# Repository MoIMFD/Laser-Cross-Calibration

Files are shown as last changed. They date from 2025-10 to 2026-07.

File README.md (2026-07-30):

# Laser Cross Calibration

A Python framework for non-sequential optical ray tracing, built to calibrate volumetric PIV (Particle Image Velocimetry) cameras via laser cross-calibration. It includes hardware control for driving a motorized dual-laser stage.

> **Status:** Research-grade, actively used at IMFD. Core ray tracing, materials, geometry, and optimization are stable. Some workflow steps (see [Known Gaps](#known-gaps)) still require manual glue code — see [Project Status](#project-status).

## Table of Contents

- [Concept](#concept)
- [Project Status](#project-status)
- [Repository Layout](#repository-layout)
- [Installation](#installation)
- [Core Concepts](#core-concepts)
- [Quickstart](#quickstart)
- [Inverse Optimization (Stage Positioning)](#inverse-optimization-stage-positioning)
- [Pipe Center Finder](#pipe-center-finder)
- [Hardware Control (`lcc-control-gui`)](#hardware-control-lcc-control-gui)
- [Development](#development)
- [Validation](#validation)
- [Known Gaps](#known-gaps)
- [License](#license)

## Concept

Laser cross calibration determines the 3D world position of the point where two laser beams intersect, and uses that as a calibration reference for cameras. By moving the intersection point through a measurement volume and photographing it, camera calibration can be performed without physically inserting a target into the flow — which matters when the target volume is a closed vessel, a pressurized cell, or otherwise hard to access.

For a beam through a single flat window, the intersection point can be computed analytically. Real setups usually involve several refractive interfaces (tank walls, immersion fluid, cylindrical windows, curved geometry), where refraction at each interface shifts the intersection unpredictably. This package solves that with **non-sequential ray tracing**: rays are propagated through an arbitrary set of optical interfaces, refracting or reflecting at each one according to Snell's law, until they either exit the system or run out of interfaces to hit.

The output is an estimate of the intersection point in world coordinates, accurate enough to serve as an initial calibration that can be refined with volume self-calibration or similar downstream methods.

## Project Status

| Area | State |
|---|---|
| Ray tracing engine (`tracing/`) | Stable, used in production |
| Surfaces: plane, cylinders, triangulated STL (`surfaces/`) | Stable |
| Materials: constant index, Sellmeier glass, mixtures (`materials/`) | Stable |
| Laser sources: single beam, dual-beam stage (`sources/`) | Stable |
| Inverse optimization (target point → stage position) (`optimization/`) | Working, see `examples/advanced-curved-geometry.ipynb` |
| Pipe center finder (`geometry/`) | Working, used for post-hoc pipe geometry extraction |
| Visualization (`visualization/`) | Working (Plotly-based interactive scenes) |
| Hardware control GUI (`lcc-control-gui/`) | Functional, production-tested with Marlin firmware |
| G-code generation from optimization results | Manual bridge only, no library API — see [Known Gaps](#known-gaps) |

Validated against published experimental data (Gunady et al., 2024) — see [Validation](#validation).

## Repository Layout

```
src/laser_cross_calibration/   Core ray tracing library (this package)
├── tracing/                   OpticalSystem, OpticalInterface, OpticalRay, RayTracer
├── surfaces/                  Plane, cylinders, triangulated (STL) surfaces
├── materials/                 Refractive index models + material registry
├── sources/                   Laser beam source definitions
├── optimization/              Inverse kinematics (target point -> stage position)
├── geometry/                  Pipe center finder (chord-fitting geometry)
└── visualization/             Plotly-based 3D scene rendering

lcc-control-gui/                Separate installable package (uv workspace member)
├── src/lcc_control_gui/       PySide6 GUI + StageController for Marlin-based stages
├── firmware/                  ESP32/Arduino mock Marlin firmware for testing without hardware
└── README.md                  Full GUI usage guide — read this before running the stage

examples/                       Jupyter tutorials
├── introduction-tutorial.ipynb  Start here: flat-plate system, Gunady et al. validation
├── advanced-curved-geometry.ipynb  STL geometry, sampling + Optimizer, calibration grid, G-code
└── stl-files/                  Example STL geometry used by the notebooks above

tests/                          pytest suite for the core library
```

## Installation

Requires **Python ≥ 3.12**. The project uses [uv](https://docs.astral.sh/uv/) and is set up as a workspace with `lcc-control-gui` as a member, so a single `uv sync` installs both the ray tracing library and the GUI:

```bash
git clone git@gitlab.hrz.tu-chemnitz.de:fluid-imfd/experiment/laser-cross-calibration.git
cd laser-cross-calibration
uv sync
```

To also pull the optional example-notebook dependency (mermaid diagram rendering):

```bash
uv sync --extra examples
```

Without `uv`, a standard editable install also works:

```bash
pip install -e .
pip install -e ./lcc-control-gui   # only if you need the hardware GUI
```

The core library depends on [`hazy-frames`](https://pypi.org/project/hazy-frames/) (published on PyPI) for coordinate frame management — no separate setup needed, it installs like any other dependency.

## Core Concepts

### Interfaces, not ambient media

Rather than tracking "what medium is the ray currently in" globally, every `OpticalInterface` explicitly names the material on both sides:

```python
OpticalInterface(
    geometry=plane_surface,
    material_pre=lcc.materials.AIR,             # side the ray approaches from
    material_post=lcc.materials.GLASS_FUSED_SILICA,  # side the ray continues into
)
```

**The surface normal must point from `material_post` toward `material_pre`** — i.e., outward from the transmitted medium:

Requires Python >= 3.12. Managed with [uv](https://docs.astral.sh/uv/).

```bash
# Install the core library in development mode
uv sync

# Optionally install the control GUI
uv pip install -e ./lcc-control-gui

# Install example notebook dependencies
uv sync --extra examples
```

This resolves what would otherwise be ambiguous for nested surfaces or re-entrant geometry, and matches how optical engineers usually reason about coatings and interfaces. Getting a normal backwards is the most common source of "rays refract the wrong way" bugs — when working from STL files, check normals visually in Blender before importing:

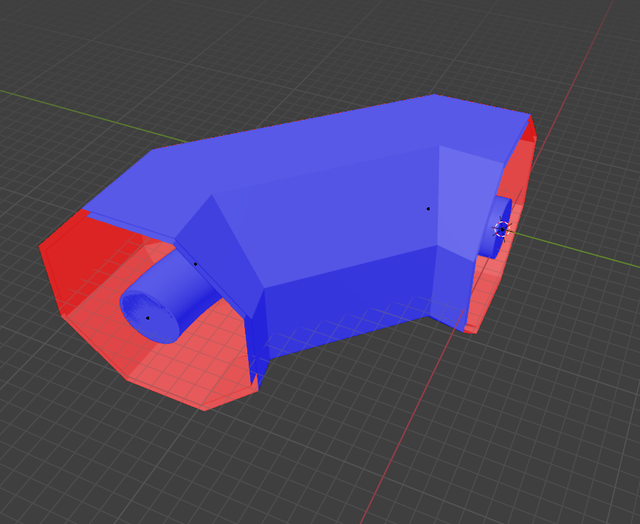
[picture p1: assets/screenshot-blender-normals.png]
Surface normal visualization in Blender


<details>
<summary>Checking normals in Blender</summary>

1. **Import your STL file**: `File -> Import -> STL`
2. **Enter Edit Mode**: select the object, press `Tab`
3. **Enable face orientation overlay**: overlay options (top-right) → check "Face Orientation"
   - Blue faces = normal points toward camera (outward)
   - Red faces = normal points away from camera (inward)
4. Optionally enable "Normals" → "Face" to see the actual vectors

For an air-to-glass interface, the normal should point toward air (outward from glass); for glass-to-air, toward glass.
</details>

### Building blocks

| Concept | Class | Role |
|---|---|---|
| Geometry | `Surface` (`Plane`, `InfiniteCylinder`, `FiniteCylinder`, `EllipticCylinder`, `TriSurface`) | Shape and location of a boundary. `TriSurface` loads STL meshes, with optional smooth (Gouraud-style) normal interpolation. |
| Material | `BaseMaterial` (`ConstantMaterial`, `SellmeierGlass`, `WaterGlycerolMixture`) | Refractive index, optionally wavelength-dependent. Look one up from the built-in registry via `lcc.materials.get_material("BK7")`. |
| Interface | `OpticalInterface` | Pairs a `Surface` with `material_pre` / `material_post`. |
| System | `OpticalSystem` | Container for all interfaces a ray can hit. `final_propagation_distance` controls how far rays travel after the last interface, so intersections downstream can still be found. |
| Source | `LaserSource` (`SingleLaserSource`, `DualLaserStageSource`) | Where beams originate. `DualLaserStageSource` models two beams fixed to a common stage origin (`arm1`/`arm2` offsets, one direction each) — the actual use case for cross-calibration. |
| Tracer | `RayTracer` | Traces sources through a system non-sequentially (closest-hit-first) and locates beam intersections. |
| Scene | `Scene` | Interactive Plotly 3D visualization of systems, sources, traced rays, and points. |

Coordinate handling goes through [`hazy`](https://pypi.org/project/hazy-frames/) (`Frame`, `Point`, `Vector`), which enforces which frame a quantity is expressed in and handles the transformations between stage, laser, and world frames automatically.

## Quickstart

This reproduces the core of `examples/introduction-tutorial.ipynb` (a glass plate submerged in water, dual-laser stage 30 cm away):

```python
from math import radians, sin, cos
import laser_cross_calibration as lcc
from hazy import Frame

# 1. Build the optical system: two interfaces forming a 1 cm glass plate in water
system = lcc.tracing.OpticalSystem(final_propagation_distance=10)
root = Frame(name="root")
surface_frame = root.make_child(name="Surface Frame")

front = lcc.tracing.OpticalInterface(
    geometry=lcc.surfaces.Plane(point=surface_frame.origin, normal=surface_frame.y_axis),
    material_pre=lcc.materials.AIR,
    material_post=lcc.materials.GLASS_FUSED_SILICA,
)
back = lcc.tracing.OpticalInterface(
    geometry=lcc.surfaces.Plane(
        point=surface_frame.origin + surface_frame.y_axis * 0.01, normal=surface_frame.y_axis
    ),
    material_pre=lcc.materials.GLASS_FUSED_SILICA,
    material_post=lcc.materials.WATER,
)
system.add_interface(front)
system.add_interface(back)

# 2. Define the dual-laser stage source (child of the same root frame)
stage_frame = root.make_child(name="Stage Frame")
alpha, beta = radians(11.5), radians(12.6)
source = lcc.sources.DualLaserStageSource(
    origin=stage_frame.origin - stage_frame.y_axis * 0.3,
    arm1=stage_frame.x_axis * 0.1,
    arm2=-stage_frame.x_axis * 0.1,
    direction1=stage_frame.vector(-sin(alpha), cos(alpha), 0.0),
    direction2=stage_frame.vector(sin(beta), cos(beta), 0.0),
)

# 3. Trace and find where the beams cross
tracer = lcc.tracing.RayTracer().add_optical_system(system=system)
rays, intersections = tracer.trace_and_find_crossings(sources=[source])
print(intersections[0])  # world-frame (x, y, z) of the beam crossing

# 4. Visualize (optional)
scene = lcc.visualization.Scene()
scene.add_system(system)
scene.add_source(source)
scene.add_rays(rays=rays)
scene.make_figure()
```

For the full walkthrough (including moving the stage and validating against Gunady et al.'s published scaling factor), see `examples/introduction-tutorial.ipynb`.

## Inverse Optimization (Stage Positioning)

Tracing answers "given a stage position, where do the beams cross?" The `optimization` module answers the inverse: **given a target 3D point, what stage position produces it?**

```python
from laser_cross_calibration.optimization import GradientBoostingEstimator, Optimizer

# Estimator gives a fast initial guess (train it on sampled stage-position -> intersection data first)
estimator = GradientBoostingEstimator(frame=stage_frame).fit(X=sampled_targets, y=sampled_origins)

optimizer = Optimizer(tracer=tracer, estimator=estimator)
result = optimizer.find_source_origin(target=target_point, source=source)
# result.x -> stage origin (Point) that places the intersection at `target`, to within ~1 µm
```

Internally this is two-phase: a gradient-boosting regressor trained on sampled `(target, stage_origin)` pairs gives a coarse initial guess, then `scipy.optimize.minimize` (Nelder-Mead — gradient-free) refines it to the tolerances defined on `Optimizer` (`POSITION_TOLERANCE`, `ERROR_TOLERANCE`).

`examples/advanced-curved-geometry.ipynb` walks through the full workflow end to end: sampling a stage's reachable volume, training the estimator, refining with `Optimizer`, generating a snake-ordered calibration grid, and exporting G-code.

## Pipe Center Finder

`laser_cross_calibration.geometry.PipeCenterFinder` fits chord-length data (from laser-cross intersections recorded at different z positions inside a cylindrical pipe) to recover the pipe's centerline, using a parabolic fit of chord-length² vs. z rather than a direct ellipse fit — this avoids the numerical degeneracy that direct ellipse fitting runs into near-circular cross-sections. Uncertainty is propagated through via the `uncertainties` package, so results carry error bars derived from the input measurement noise.

## Hardware Control (`lcc-control-gui`)

A separate installable package (uv workspace member) providing a PySide6 GUI and a `StageController` class for driving a Marlin-firmware-based motion stage (standard 3D-printer firmware/G-code) over serial. It can be used headless for scripted moves, or through the GUI for manual jogging and G-code file execution. Jupyter notebooks are also a great way for interactive control and looping through positions.

**See [`lcc-control-gui/README.md`](lcc-control-gui/README.md) for installation, first-time setup, and the scripting API** — it's kept up to date independently since it has its own release cycle within the workspace.

A mock Marlin firmware for an ESP32/Arduino is included in `lcc-control-gui/firmware/`, useful for testing the GUI/controller without physical hardware attached.

## Development

```bash
uv sync                       # installs dev dependency group (pytest, ruff, pre-commit, ...)
uv run pytest                 # core library tests
uv run pytest --cov           # with coverage (see pyproject.toml [tool.coverage])
cd lcc-control-gui && uv run pytest tests/   # GUI package has its own test suite
uv run ruff check .
pre-commit install            # enable lint/format hooks before committing
```

Test markers `unit`, `integration`, and `slow` are registered in `pyproject.toml` and can be selected with `pytest -m <marker>`.

There is no CI pipeline configured yet — tests and linting are currently run locally / via pre-commit hooks only.

## Validation

The framework's ray tracing has been validated against the experimental setup published by Gunady et al. (2024, [DOI: 10.1088/1361-6501/ad574d](https://iopscience.iop.org/article/10.1088/1361-6501/ad574d)): a dual-laser stage at fixed angles (11.5° / 12.6°) shining through a fused-silica plate into water. The published relationship between stage displacement and intersection-point displacement is a scaling factor of **1.34**; the simulation reproduces **1.343** (R ≈ 1.0), see `examples/introduction-tutorial.ipynb`.

## Known Gaps

Things a new maintainer should be aware of before assuming the pipeline is end-to-end automated:

- **No first-class G-code generator.** `Optimizer.find_source_origin` returns stage positions, but nothing currently converts a list of those into a `.gcode` file for `StageController.run_gcode_file` as a proper library function — `examples/advanced-curved-geometry.ipynb` shows the manual bridge (convert to machine coordinates via one measured reference point, wrap in dwell/trigger G-code), but it's still copy-paste-and-adapt per experiment, not an API.
- **No example notebook for the `geometry` module** (`PipeCenterFinder`). Tracing and optimization are both covered end-to-end in `examples/`.
- **No LICENSE file yet.** The maintainer intends MIT (all code is original or built on permissively-licensed dependencies) but this hasn't been formally added — do this before sharing the repository outside the institute.
- **No CI.** Linting and tests are enforced via local pre-commit hooks only; nothing runs automatically on push/merge requests.
- **No partial reflection / beam splitting.** `OpticalRay.refract` is a hard either/or: below the critical angle the ray fully refracts (100% transmission assumed, no Fresnel reflectance computed at all), above it the ray fully reflects (total internal reflection). Real interfaces always partially reflect some of the incident beam too, even below the critical angle — that portion is currently discarded rather than traced as a second, lower-intensity ray, and `OpticalRay` has no intensity/amplitude field to represent it if it were. Doesn't affect the primary calibration use case (only the dominant transmitted beam matters for finding the crossing point), but would matter for stray-light or ghost-reflection analysis.

## License

MIT (intended — see [Known Gaps](#known-gaps); no `LICENSE` file has been added to the repository yet).

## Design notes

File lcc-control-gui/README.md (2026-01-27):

# Laser Cross Calibration - Control GUI

## Description

PySide6 GUI application for controlling a Marlin-based laser cross calibration stage via serial communication and G-code commands.

**Architecture:**
```
GUI → StageController → SerialInterface → Serial Port (Marlin Firmware)
```

The `StageController` can also be used directly in Python scripts for automated control without the GUI.

### Features

- Manual movement control with configurable step sizes (0.1, 1, 10, 100 mm)
- Acceleration configuration
- Emergency stop (M410 G-code)
- Automatic serial port scanning
- G-code file execution with progress tracking
- Real-time position monitoring
- Multi-threaded serial communication (non-blocking GUI)

## Installation

**Requirements:**
- Python ≥ 3.12
- PySide6 >= 6.9.2
- pyserial >= 3.5
- colorama >= 0.4.6

**Install from main project:**
```bash
cd ..  # Navigate to main project directory
uv pip install -e ./lcc-control-gui
```

**Or install standalone:**
```bash
cd lcc-control-gui
uv pip install -e .
```

## Usage

### Running the GUI

```bash
# From anywhere after installation
python -m lcc_control_gui

# Or from this directory
python -m lcc_control_gui
```

### First-time Setup

1. Connect the stage controller via USB
2. Launch the GUI
3. Select the serial port from the dropdown (e.g., `/dev/ttyUSB0` on Linux, `COM3` on Windows)
4. Click **Connect**
5. Wait for connection status: ● Connected
6. Click **Home Axes** to initialize the stage position

### Manual Movement

1. Select step size (100, 10, 1, or 0.1 mm) using the radio buttons
2. Click the direction buttons (X+, X-, Y+, Y-, Z+, Z-) to move
3. Current position updates automatically in the status bar
4. Use **Go Home** to return to (0, 0, 0)

### G-code File Execution

1. Click **Browse...** to select a `.gcode` file
2. Click **Run GCode**
3. Monitor the progress bar
4. Click **Emergency Stop** if needed

### Scripting with StageController

The `StageController` can be used directly in Python for automated tasks:

```python
from lcc_control_gui.serial_interface import SerialInterface
from lcc_control_gui.stage_controller import StageController

# Initialize serial connection
serial_if = SerialInterface(port="/dev/ttyUSB0", baud_rate=115200)

# Create stage controller
stage = StageController(serial_if)

# Home all axes
stage.home_axes()

# Move to absolute position
stage.move_absolute(x=10.0, y=20.0, z=5.0, feedrate=1000.0)

# Read current position
position = stage.read_position()
print(f"Current position: {position}")

# Run G-code file
stage.run_gcode_file("path/to/file.gcode")

# Clean up
serial_if.close()
```

## Development

### Running Tests

```bash
pytest tests/
```

### Test Device

A simple test device firmware for ESP32 (also compatible with Arduino) is provided in `firmware/`:

```bash
cd firmware
platformio run --target upload
```

This creates a mock Marlin controller for testing the GUI without physical hardware.

## Technical Notes

- **Serial Baud Rate:** 115200 (standard for Marlin)
- **Position Polling:** 1000ms interval
- **Threading:** Serial communication runs in a background thread to prevent GUI blocking
- **G-code Standard:** Marlin-compatible commands (see [Marlin G-code Documentation](https://marlinfw.org/docs/gcode/G000-G001.html))

## Future Enhancements

- Logging via loguru
- Text field for custom G-code commands
- Save/load movement presets
- Position history and visualization

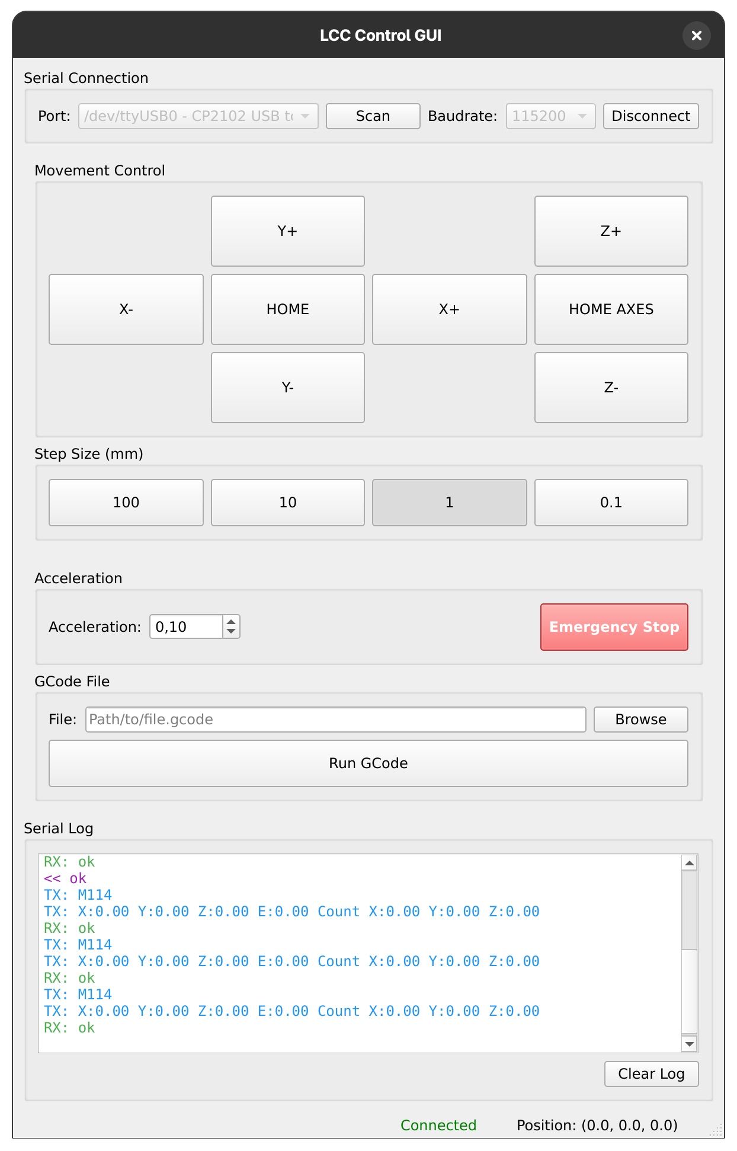
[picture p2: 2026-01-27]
lcc-control-gui/assets/GUI-screenshot.png

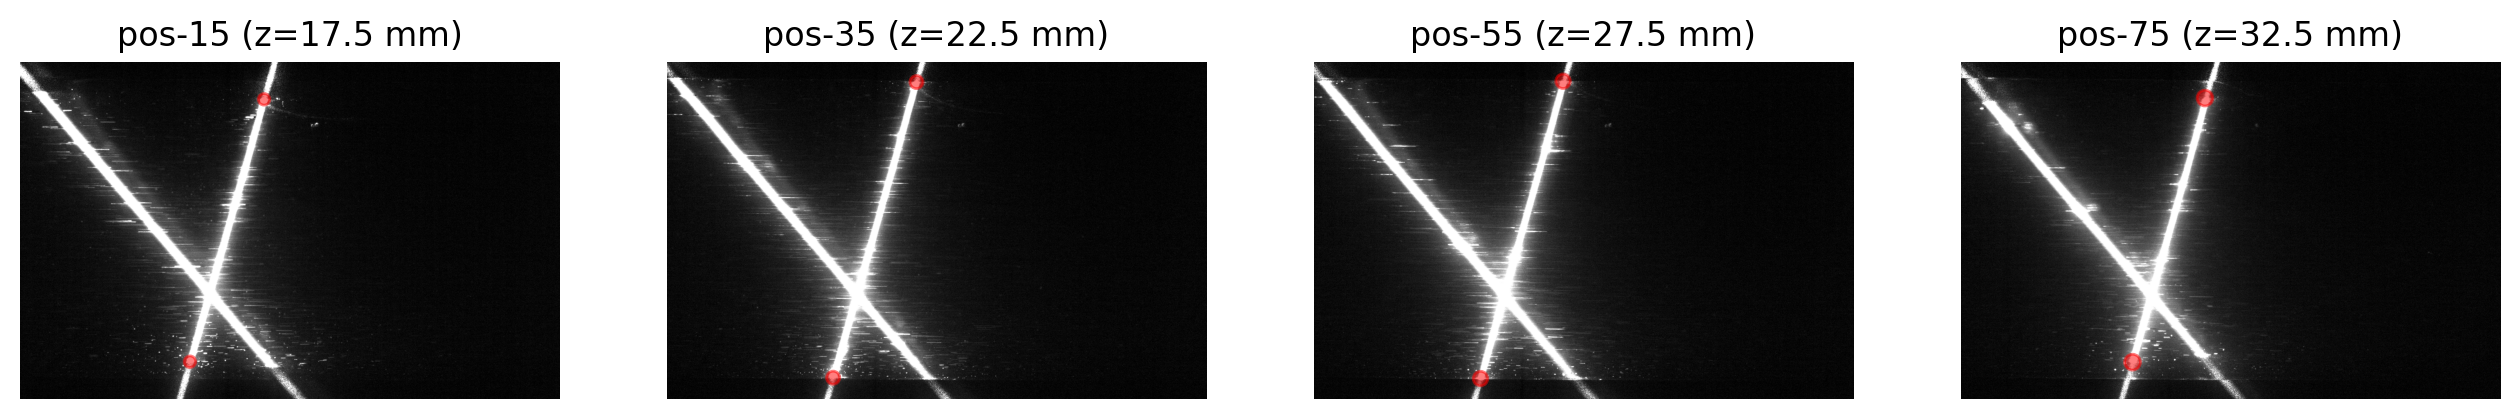
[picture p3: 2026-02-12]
examples/images/pipe-wall-intersections.png

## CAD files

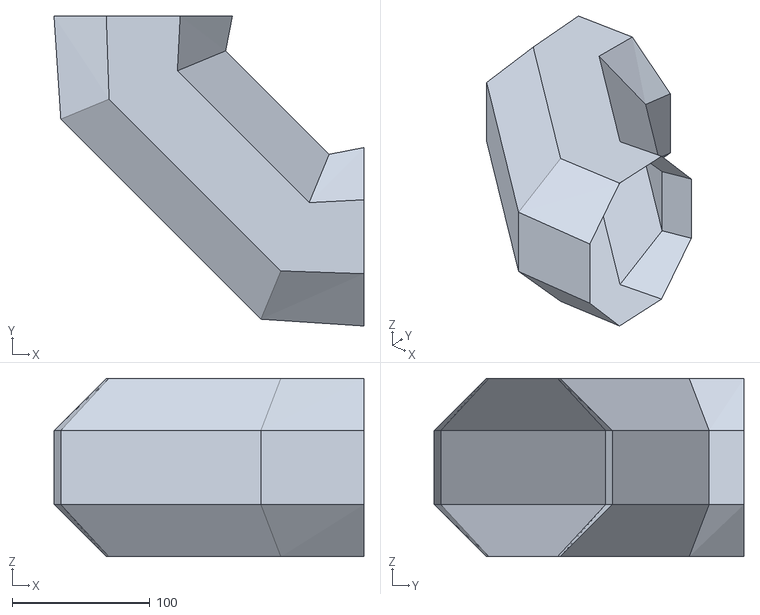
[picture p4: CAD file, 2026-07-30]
examples/stl-files/simple-octagone-inner.stl
224.7 x 224.7 x 129.3

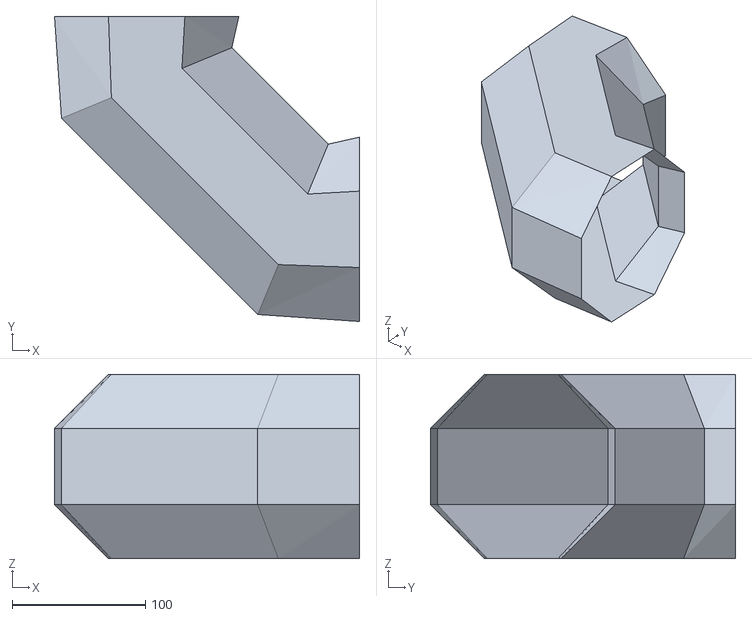
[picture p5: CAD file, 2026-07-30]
examples/stl-files/simple-octagone-outer.stl
229.3 x 229.3 x 138.6

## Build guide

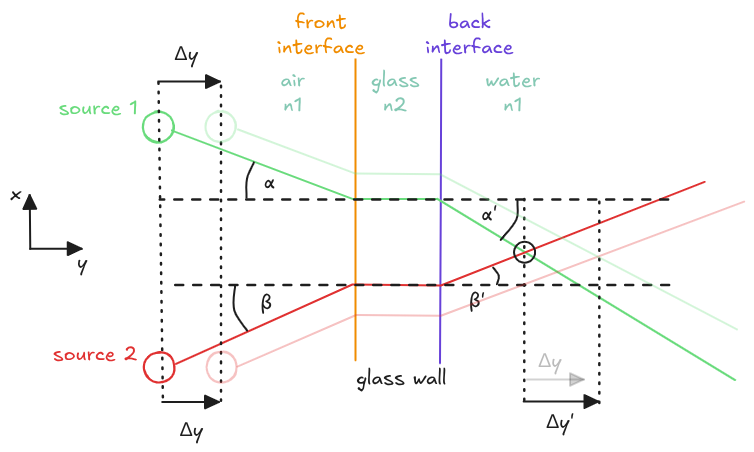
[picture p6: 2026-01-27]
examples/images/gunady_setup_sketch.png

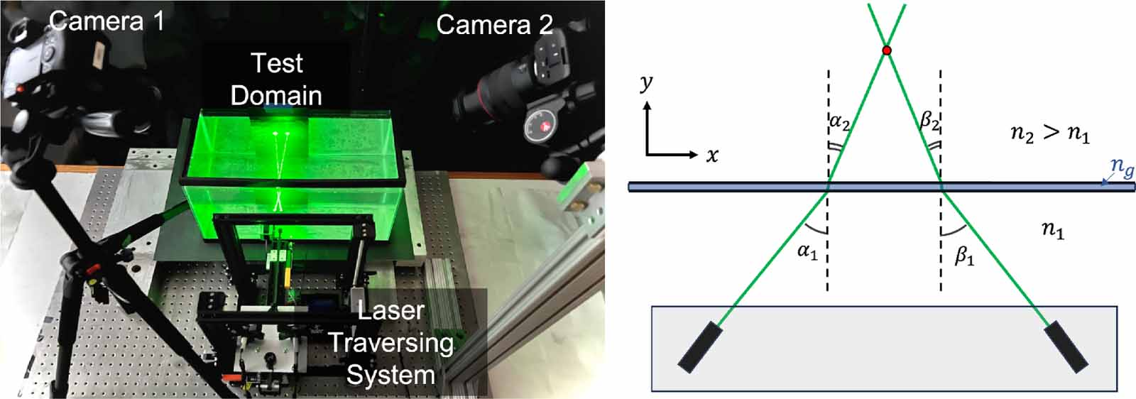
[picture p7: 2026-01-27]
examples/images/gunady_setup.png

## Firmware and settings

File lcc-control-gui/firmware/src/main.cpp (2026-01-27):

#include <Arduino.h>

struct Position {
  float x;
  float y;
  float z;
};

struct MachineState {
  Position current;
  Position target;
  bool absoluteMode;
  bool isHomed;
  bool isMoving;
  float feedrate;
  float acceleration;
  float maxFeedrateX;
  float maxFeedrateY;
  float maxFeedrateZ;
  unsigned long moveStartTime;
  unsigned long moveDuration;
};

MachineState state = {
  {0.0, 0.0, 0.0},
  {0.0, 0.0, 0.0},
  true,
  false,
  false,
  1000.0,
  500.0,
  5000.0,
  5000.0,
  5000.0,
  0,
  0
};

void handleCommand(String cmd);
void updateMovement();
float parseValue(String cmd, char axis);
bool hasParameter(String cmd, char param);
float calculateDistance(Position from, Position to);
unsigned long calculateMoveDuration(float distance, float feedrate);

void setup() {
  Serial.begin(115200);
  Serial.setTimeout(100);
  delay(1000);

  Serial.println("start");
  Serial.println("Marlin 2.0.0");
  Serial.println("echo:  Last Updated: 2024-01-01 12:00");
  Serial.println("echo: Compiled: Jan  1 2024");
  Serial.println("echo: Free Memory: 32768");
  Serial.println("echo:Hardcoded Default Settings Loaded");
}

void loop() {
  updateMovement();

  if (Serial.available()) {
    String cmd = Serial.readStringUntil('\n');
    cmd.trim();

    if (cmd.length() > 0) {
      handleCommand(cmd);
    }
  }
}

void updateMovement() {
  if (!state.isMoving) return;

  unsigned long elapsed = millis() - state.moveStartTime;
  if (elapsed >= state.moveDuration) {
    state.current = state.target;
    state.isMoving = false;
  } else {
    float progress = (float)elapsed / state.moveDuration;
    state.current.x = state.current.x + (state.target.x - state.current.x) * progress;
    state.current.y = state.current.y + (state.target.y - state.current.y) * progress;
    state.current.z = state.current.z + (state.target.z - state.current.z) * progress;
  }
}

float parseValue(String cmd, char param) {
  int idx = cmd.indexOf(param);
  if (idx == -1) return 0.0;
  return cmd.substring(idx + 1).toFloat();
}

bool hasParameter(String cmd, char param) {
  return cmd.indexOf(param) != -1;
}

float calculateDistance(Position from, Position to) {
  float dx = to.x - from.x;
  float dy = to.y - from.y;
  float dz = to.z - from.z;
  return sqrt(dx*dx + dy*dy + dz*dz);
}

unsigned long calculateMoveDuration(float distance, float feedrate) {
  if (feedrate <= 0) feedrate = 1000.0;
  return (unsigned long)((distance / feedrate) * 60000.0);
}

void handleCommand(String cmd) {
  delay(10);

  if (cmd.startsWith("M112")) {
    Serial.println("echo:EMERGENCY STOP");
    state.isMoving = false;
    Serial.println("ok");
  }
  else if (cmd.startsWith("G28")) {
    Serial.println("echo:Homing");

    bool homeX = !hasParameter(cmd, 'X') && !hasParameter(cmd, 'Y') && !hasParameter(cmd, 'Z');
    bool homeY = homeX;
    bool homeZ = homeX;

    if (!homeX) {
      homeX = hasParameter(cmd, 'X');
      homeY = hasParameter(cmd, 'Y');
      homeZ = hasParameter(cmd, 'Z');
    }

    delay(500);

    if (homeX) {
      state.current.x = 0.0;
      state.target.x = 0.0;
      Serial.println("echo:  Home X");
    }
    if (homeY) {
      state.current.y = 0.0;
      state.target.y = 0.0;
      Serial.println("echo:  Home Y");
    }
    if (homeZ) {
      state.current.z = 0.0;
      state.target.z = 0.0;
      Serial.println("echo:  Home Z");
    }

    state.isHomed = true;
    state.isMoving = false;
    Serial.println("ok");
  }
  else if (cmd.startsWith("M114")) {
    char buffer[128];
    snprintf(buffer, sizeof(buffer),
             "X:%.2f Y:%.2f Z:%.2f E:0.00 Count X:%.2f Y:%.2f Z:%.2f",
             state.current.x, state.current.y, state.current.z,
             state.current.x, state.current.y, state.current.z);
    Serial.println(buffer);
    Serial.println("ok");
  }
  else if (cmd.startsWith("G90")) {
    state.absoluteMode = true;
    Serial.println("ok");
  }
  else if (cmd.startsWith("G91")) {
    state.absoluteMode = false;
    Serial.println("ok");
  }
  else if (cmd.startsWith("G0") || cmd.startsWith("G1")) {
    Position newTarget = state.current;

    if (hasParameter(cmd, 'X')) {
      float x = parseValue(cmd, 'X');
      newTarget.x = state.absoluteMode ? x : state.current.x + x;
    }
    if (hasParameter(cmd, 'Y')) {
      float y = parseValue(cmd, 'Y');
      newTarget.y = state.absoluteMode ? y : state.current.y + y;
    }
    if (hasParameter(cmd, 'Z')) {
      float z = parseValue(cmd, 'Z');
      newTarget.z = state.absoluteMode ? z : state.current.z + z;
    }
    if (hasParameter(cmd, 'F')) {
      state.feedrate = parseValue(cmd, 'F');
    }

    float distance = calculateDistance(state.current, newTarget);
    if (distance > 0.001) {
      state.target = newTarget;
      state.isMoving = true;
      state.moveStartTime = millis();
      state.moveDuration = calculateMoveDuration(distance, state.feedrate);
    }

    Serial.println("ok");
  }
  else if (cmd.startsWith("M204")) {
    if (hasParameter(cmd, 'P')) {
      state.acceleration = parseValue(cmd, 'P');
      Serial.print("echo:Acceleration set to ");
      Serial.println(state.acceleration);
    }
    Serial.println("ok");
  }
  else if (cmd.startsWith("M203")) {
    if (hasParameter(cmd, 'X')) {
      state.maxFeedrateX = parseValue(cmd, 'X');
    }
    if (hasParameter(cmd, 'Y')) {
      state.maxFeedrateY = parseValue(cmd, 'Y');
    }
    if (hasParameter(cmd, 'Z')) {
      state.maxFeedrateZ = parseValue(cmd, 'Z');
    }
    Serial.println("echo:Max feedrate updated");
    Serial.println("ok");
  }
  else if (cmd.startsWith("M42")) {
    int pin = 67;
    int value = 0;

    if (hasParameter(cmd, 'P')) {
      pin = (int)parseValue(cmd, 'P');
    }
    if (hasParameter(cmd, 'S')) {
      value = (int)parseValue(cmd, 'S');
    }

    Serial.print("echo:Pin ");
    Serial.print(pin);
    Serial.print(" set to ");
    Serial.println(value);
    Serial.println("ok");
  }
  else if (cmd.startsWith("M502")) {
    Serial.println("echo:Hard Reset");
    state.acceleration = 500.0;
    state.maxFeedrateX = 5000.0;
    state.maxFeedrateY = 5000.0;
    state.maxFeedrateZ = 5000.0;
    state.feedrate = 1000.0;
    Serial.println("ok");
  }
  else if (cmd.startsWith("M115")) {
    Serial.println("FIRMWARE_NAME:Marlin 2.0.0 (Simulator)");
    Serial.println("FIRMWARE_URL:https://github.com");
    Serial.println("PROTOCOL_VERSION:1.0");
    Serial.println("MACHINE_TYPE:3D Printer");
    Serial.println("EXTRUDER_COUNT:0");
    Serial.println("UUID:00000000-0000-0000-0000-000000000000");
    Serial.println("ok");
  }
  else if (cmd.startsWith("G4")) {
    int ms = 0;
    if (hasParameter(cmd, 'P')) {
      ms = (int)parseValue(cmd, 'P');
    } else if (hasParameter(cmd, 'S')) {
      ms = (int)(parseValue(cmd, 'S') * 1000);
    }

    Serial.print("echo:Dwell ");
    Serial.print(ms);
    Serial.println("ms");
    delay(min(ms, 5000));
    Serial.println("ok");
  }
  else {
    Serial.println("ok");
  }
}

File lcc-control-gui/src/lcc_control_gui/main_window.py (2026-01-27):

from __future__ import annotations

import threading
from typing import TYPE_CHECKING

from PySide6.QtCore import QObject, QTimer, Signal
from PySide6.QtWidgets import QLabel, QMainWindow, QVBoxLayout, QWidget

from .serial_interface import SerialInterface
from .stage_controller import StageController
from .widgets import GCodeWidget, LogWidget, MovementWidget, StatusWidget

if TYPE_CHECKING:
    from pathlib import Path


class ConnectionWorker(QObject):
    finished = Signal(bool, object, object)
    error = Signal(str)

    def __init__(
        self,
        port: str,
        baudrate: int,
        command_callback=None,
        log_callback=None,
        unsolicited_callback=None,
    ):
        super().__init__()
        self.port = port
        self.baudrate = baudrate
        self.command_callback = command_callback
        self.log_callback = log_callback
        self.unsolicited_callback = unsolicited_callback

    def run(self):
        try:
            serial_interface = SerialInterface(
                self.port,
                baud_rate=self.baudrate,
                command_msg_callback=self.command_callback,
                log_msg_callback=self.log_callback,
                unsolicited_msg_callback=self.unsolicited_callback,
            )
            stage_controller = StageController(serial_interface)
            self.finished.emit(True, serial_interface, stage_controller)
        except Exception as e:
            self.error.emit(str(e))
            self.finished.emit(False, None, None)


class MainWindow(QMainWindow):
    log_command_signal = Signal(str, object, str)
    log_message_signal = Signal(object, str)
    log_unsolicited_signal = Signal(str)
    position_update_signal = Signal(float, float, float)

    def __init__(self):
        super().__init__()
        self.serial_interface: SerialInterface | None = None
        self.stage_controller: StageController | None = None
        self.position_timer = None

        self.setWindowTitle("LCC Control GUI")
        self.setMinimumSize(600, 700)

        self._init_statusbar()
        self._init_ui()

    def _init_statusbar(self):
        statusbar = self.statusBar()

        self.status_connection_label = QLabel("Disconnected")
        self.status_connection_label.setStyleSheet("color: red; padding: 0 10px;")

        self.status_position_label = QLabel("Position: (0.0, 0.0, 0.0)")
        self.status_position_label.setStyleSheet("padding: 0 10px;")

        statusbar.addPermanentWidget(self.status_connection_label)
        statusbar.addPermanentWidget(self.status_position_label)

    def _init_ui(self):
        central_widget = QWidget()
        self.setCentralWidget(central_widget)

        layout = QVBoxLayout(central_widget)

        self.connection_widget = StatusWidget()
        self.movement_widget = MovementWidget()
        self.gcode_widget = GCodeWidget()
        self.log_widget = LogWidget()

        layout.addWidget(self.connection_widget)
        layout.addWidget(self.movement_widget)
        layout.addWidget(self.gcode_widget)
        layout.addWidget(self.log_widget)
        layout.addStretch()

        self.connection_widget.connect_requested.connect(self._connect_serial)
        self.connection_widget.disconnect_requested.connect(self._disconnect_serial)
        self.movement_widget.move_requested.connect(self._handle_move)
        self.movement_widget.home_requested.connect(self._handle_home)
        self.movement_widget.home_axes_requested.connect(self._handle_home_axes)
        self.gcode_widget.run_gcode_requested.connect(self._handle_run_gcode)
        self.gcode_widget.acceleration_changed.connect(self._handle_acceleration_change)
        self.gcode_widget.emergency_stop_requested.connect(self._handle_emergency_stop)

        self.log_command_signal.connect(self.log_widget.log_command)
        self.log_message_signal.connect(self._log_message_slot)
        self.log_unsolicited_signal.connect(self.log_widget.log_unsolicited)
        self.position_update_signal.connect(self._update_position_display)

    def _connect_serial(self, port: str, baudrate: int):
        self.connection_worker = ConnectionWorker(
            port,
            baudrate,
            command_callback=self._log_command,
            log_callback=self._log_message,
            unsolicited_callback=self._log_unsolicited,
        )
        self.connection_thread = threading.Thread(
            target=self.connection_worker.run, daemon=True
        )
        self.connection_worker.finished.connect(self._on_connection_finished)
        self.connection_worker.error.connect(self._on_connection_error)
        self.connection_thread.start()

    def _on_connection_finished(self, success: bool, serial_if, stage_ctrl):
        if success:
            self.serial_interface = serial_if
            self.stage_controller = stage_ctrl
            self.connection_widget.set_connection_status(True)
            self.gcode_widget.set_enabled(True)
            self.status_connection_label.setText("Connected")
            self.status_connection_label.setStyleSheet("color: green; padding: 0 10px;")

            self.position_timer = QTimer()
            self.position_timer.timeout.connect(self._update_position)
            self.position_timer.start(1000)
        else:
            self.connection_widget.set_connection_status(False)
            self.gcode_widget.set_enabled(False)
            self.status_connection_label.setText("Disconnected")
            self.status_connection_label.setStyleSheet("color: red; padding: 0 10px;")

    def _on_connection_error(self, error_msg: str):
        print(f"Failed to connect: {error_msg}")

    def _disconnect_serial(self):
        if self.position_timer:
            self.position_timer.stop()
            self.position_timer = None
        if self.serial_interface:
            self.serial_interface.close()
            self.serial_interface = None
        if self.stage_controller:
            self.stage_controller = None

        self.connection_widget.set_connection_status(False)
        self.gcode_widget.set_enabled(False)
        self.status_connection_label.setText("Disconnected")
        self.status_connection_label.setStyleSheet("color: red; padding: 0 10px;")
        self.status_position_label.setText("Position: (0.0, 0.0, 0.0)")

    def _log_command(self, command: str, status, response: str):
        self.log_command_signal.emit(command, status, response)

    def _log_message(self, level, message: str):
        self.log_message_signal.emit(level, message)

    def _log_message_slot(self, level, message: str):
        level_str = level.value if hasattr(level, "value") else str(level)
        self.log_widget.log_info(message, level_str)

    def _log_unsolicited(self, message: str):
        self.log_unsolicited_signal.emit(message)
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

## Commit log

2025-10-27 Major architecture refactor: implement comprehensive ray tracing and calibration system
    This commit introduces a complete redesign of the laser
    cross-calibration system with:
    ## Core System Components
    - **Ray Tracing Engine**: Full 3D optical ray propagation with Snell's
    law refraction
    - Multi-surface geometry support (planes, rectangles, cylinders,
    elliptic cylinders)
    - Precise ray-surface intersection algorithms with numerical stability
    - Interactive 3D visualization using Plotly
    - **Calibration Framework**: Unified calibration point and stage
    positioning system
    - CalibrationPoint data structure linking 3D intersections to stage
    positions
    - Motorized 3-axis Stage class with coo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
2025-10-27 Major ray tracing and materials system enhancement
2026-01-27 restructure architecture and interfaces
    The old design was not flexible regarding system creation and mixing
    components. A new design approach is chosen where key components are
    defined by base classes or abstract base classes and the final system is
    created by composition. This approach is flexibil and can be extended
    easily from here. The gcode module is removed for now but maybe re
    initiated after the optimization module works or out sourced.
    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
2026-01-27 formatted project and cleaned gitignore
    Changes:
    - removed personal ignores from the project git ignore into
    .git/info/exclude
    - formatted and linted project with ruff
    - inserted TYPE_CHECKING guards where needed
    [WIP] remove legacy method
2026-01-27 refactor: remove linear stage config and improve test fixtures
    - Remove obsolete device configurations
    - Rename stl.py to triangulated.py
    - Add extensive ray fixtures for testing
    - Expand TriangulatedSurface test coverage
2026-01-27 feat(gui): created project structure and pyproject.toml
    - Create lcc-control-gui package with src layout
    - Add pyproject.toml with PySide6, pyserial dependencies
    - Use hatchling as build backend
    - Create module structure: main_window, serial_interface, stage_controller
    - Create widget structure: movement, gcode, status widgets"
2026-01-27 feat(gui): implement SerialInterface and StageController
    Implementation inspired by: https://github.com/0x23/MicroManipulatorStepper/
    - Add threaded SerialInterface with async reader loop
    - Implement command/response synchronization with threading.Condition
    - Add automatic reconnection on connection loss
    - Implement StageController with Merlin G-code commands
    - Support home, move_relative, move_absolute, read_position
    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
2026-01-27 test(gui): implement tests for gui functionalities
    - created test for SerialInterface and StageController
    - used mocks for independent testing
    [WIP] inital version of the gui
    [WIP] create simple test device
2026-01-27 feat(gui): create initial version of GUI
    Created a PySide6 GUI for controlling the laser beam stage. The GUI
    communicates with the Marlin driver via a serial connection and GCode
    commands.
    GUI -> StageController -> SerialInterface
    A scripting of tasks and commands can be done by using the
    StageController directly in Python.
    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
2026-01-27 fix(gui): bugfix mixing of relative and absolute positions
    [stage_controller.py]
2026-01-27 fix/test: add Gunady setup as real world example
    - add the Gunady experiment as validation case
    - Reference: https://iopscience.iop.org/article/10.1088/1361-6501/ad574d
    - fix plane ray intersection:
    - accepted intersections behind ray (negative distance)
    - incorrect handling for non origin planes (part of future work on surface coordinates)
    - ray refract now matches path hisotry, position and direction
    - add auto propagation after last interaction for better visualization
    - add translate method to DualLaserStageSource
    - add Elastosil RT 601 to materials for future implementation of our setups
    TODO:
    - implement calculation of intersections in surface coordinates
    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
2026-01-27 docs: add comprehensive tutorial with Gunady setup validation
    Add detailed introduction tutorial demonstrating laser cross calibration
    framework with real-world validation against Gunady et al. publication
    (DOI: 10.1088/1361-6501/ad574d).
    Tutorial content:
    - Core concepts explanation (OpticalSystem, interfaces, materials, sources)
    - Step-by-step setup of dual-laser stage with glass plate in water
    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
2026-01-27 test: add Gunady setup integration and regression tests
    Add comprehensive test coverage for laser cross-calibration using the
    Gunady et al. experimental setup with theoretical validation.
    Integration test:
    - Validates calibration ratio (delta y_intersection / delta y_stage approx 1.34)
    - Calculates theoretical ratio from Snell's law and geometry
    - Measures actual ratio via ray tracing at multiple stage positions
    - Verifies linear relationship (R > 0.999) with 1% tolerance
    Regression test:
    - Prevents bug where rays incorrectly returned to air after glass
    - Validates correct media sequence: air -> fused silica -> water
    - Ensures rays don't revisit previous media
    Test fixtures:
    - gunady_opti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
2026-01-27 feat: add type hints and fix pyproject.toml
    - add more type hints to lcc-control-gui
    - removed legacy imports from pyproject.toml
    - fixed build pipeline for lcc-control-gui wheel
    - improve point displaying
    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
    [serial_interface.py]
2026-01-27 feat: implement hierarchical coordinate system for optical components
    Refactor core functionality to support hierarchical coordinate frames
    for increased flexibility in spatial transformations.
    - Extend coordinate system primitives with enhanced frame handling
    - Adapt LaserSource and child classes (SingleLaser, DualLaserStage)
    - Rewrite OpticalRay to use new coordinate logic
    - Update surface implementations (Plane, EllipticCylinder, InfiniteCylinder, Triangulated)
    - Remove bounded_plane surface (replaced by new implementation)
    - Update STL surface coordinate system support
    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
2026-01-27 fix: fix laser source and examples for seamless integration of cs
    - add negation method to Vector class
    - fix DualLaserStageSource to use Vector class
    - fix return types of line_segment_intersection in ray.py
    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
2026-01-27 refactor: extract coordinate functionality to hazy package
    - Remove laser_cross_calibration.coordinate_system implementation
    - Add hazy as external dependency
    - Update imports across codebase
2026-01-27 fix: update command timeout and connection validation
    - Increase default command timeout from 2s to 30s to handle long-running
    G-code commands like homing (G28)
    - Handle Marlin BUSY responses correctly by resetting timeout instead of
    returning early, matching Pronterface behavior
    - Replace fragile startup banner detection with active M105/M115 polling
    - Rename _wait_for_startup to _validate_connection
    - Add _flush_input helper method to clear serial buffer before validation
    [serial_interface.py]
2026-01-27 fix: improve serial connection with Pronterface-style polling
    - Replace passive startup banner detection with active M105 polling
    - Add _wait_until_online() that sends M105 repeatedly until device responds
    - Detect online status via greetings (start, marlin), ok, or T: responses
    - Handle BUSY responses by resetting timeout (for long-running commands)
    - Increase default command timeout from 2s to 30s for commands like G28
    - Pin pyserial to 3.4.x to fix 250000 baud on CH340 USB-serial adapters
    (pyserial 3.5 broke non-standard baud rates on Linux)
    [serial_interface.py]
2026-01-27 chore: pin pyserial version and move hazy-frames to pypi
    - pyserial 3.5 removed baudrate 250_000 which disables connection to lcc marlin driver; pinned to version <3.5
    - hazy-frames is now on PyPI
2026-01-27 feat: optimization module
    Add optimization module to calculate stage positions from desired intersections. The intersection calculation follows
    a 2-step process:
    1. Calculate an initial guess using a regression model
    2. Refine the guess using gradient-free optimization
    Adds:
    - Estimator Protocol
    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
2026-01-29 feat: add geometry module with PipeCenterFinder
    Add pipe center finding utility using chord geometry analysis:
    - PipeCenterFinder class for locating pipe centers from laser cross measurements
    - Fits ellipse parameters (z0, a, b) via parabolic L^2 model
    - Propagates uncertainties through all calculations
    - Includes visualization methods (plot, plot_ellipse)
    - version bump to 0.1.2
    - add uncertainties for error propagation
2026-02-12 docs: add pipe center finder tutorial
    Created a notebook demonstrating the PipeCenterFinder:
    - introduces the bootstrapping problem
    - demonstrates the processing chain
    - shows output validation strategies
2026-04-28 chore: removed pyserial version limit
    The Marlin controller have been updated to now use Baudrate 115 200 compatible with pyserial posix standard.
2026-07-30 test: migrate test suite to new hazy syntax
    - Update fixture from global_frame to frame() with fixture injection
    - Update hazy API calls: create_unit_* → unit_*
    - Update test assertions for hazy types (Point, Vector)
    - Re-enable ray fixtures in conftest
    - Add return self to SingleLaserSource.set_origin for method chaining
    - Fix type annotation in OpticalRay.ray_z
    - Uncomment .vscode/ in .gitignore
    All 75 tests passing.
2026-07-30 fix: use f-strings for colorama-colored prints
    colorama defines Fore/Style attributes as int class members that get
    monkey-patched to ANSI strings only at runtime, so static type
    checkers flag `Fore.X + str` as int + str. Interpolating instead of
    concatenating sidesteps the false positive.
    [serial_interface.py]
2026-07-30 fix: make serial line handling reconnect-aware and Marlin-accurate
    _handle_line mixed classification with side effects, the online status
    was a one-way latch that never reflected reconnects, and send_command
    never flushed stale input, so a delayed reply to a timed-out command
    could be misattributed to the next one. Split classification into a
    pure _classify_line, replace the online bool with a ConnectionStatus
    enum that resets and re-triggers the handshake on reconnect, flush the
    input buffer before writing, drain stray replies after the handshake,
    and detect real Marlin busy/halt messages (echo:busy:, kill()) instead
    of formats that were never actually sent on the wire.
    [serial_interface.py, test_serial_interface.py]
2026-07-30 fix: restore absolute mode after move_relative
    move_relative() switched to G91 (relative mode) for the move but never
    switched back to G90, leaving the stage in relative mode for every
    subsequent command that doesn't explicitly set its own mode - silently
    turning intended absolute-position moves into relative offsets.
    [stage_controller.py]
2026-07-30 fix: isolate line-handling errors and widen online-signal detection
    An unhandled exception inside _classify_line/_dispatch_classified_line
    was caught by the same except clause as connection loss, so a bug in
    line handling could either kill the reader thread silently or
    misfire a reconnect. Give _handle_line its own try/except so failures
    are logged without disrupting the read loop or connection state.
    Also mark busy and error replies as proof-of-life, not just ok - any
    recognized status line means the device is alive and talking.
    [serial_interface.py, test_serial_interface.py]
2026-07-30 fix: prevent spurious self-intersection on TriSurface entry
    A ray refracting through a TriSurface mesh could immediately re-hit
    the same mesh on the next intersection test, at a distance of ~1e-8 m
    caused by floating-point error in the localize/globalize round-trip.
    This flipped the tracked medium back to material_pre even though the
    ray never left material_post, corrupting refraction at the next real
    interface.
    find_next_intersection now ignores hits on the interface a ray just
    came from if they're closer than SELF_INTERSECTION_EPSILON (1e-6 m),
    while still allowing a genuine re-hit of the same interface further
    along the ray (e.g. the far wall of a tube).
2026-07-30 fix: prevent stage-origin frame mislabeling in Optimizer.find_source_origin
    find_source_origin optimized a stage origin in source.origin.frame's local
    coordinates, then returned it re-tagged with target's original frame instead
    of an actual transform. Invisible whenever target and source happened to
    share a frame, but produced the right numbers under the wrong frame label as
    soon as the stage sits in its own rotated/translated frame -- the normal
    case for a physically-mounted dual-laser stage.
2026-07-30 fix: stop trace_ray double-propagating the final ray segment
    The final_propagation_distance leg was propagated twice for any ray that
    exits the system normally: once inside the `interface is None` branch, and
    again, unconditionally, right after the loop. That doubled the last leg's
    travel distance and duplicated the last media_history entry.
    Easy to miss when the duplicated medium matched the one before it (e.g.
    "water -> water" in the flat Gunady setup, which reads as unremarkable), but
    it affected every ray that ran out of interfaces to hit, regardless of
    geometry.
2026-07-30 fix: return NaN Point instead of None from line_segment_intersection
    None forced every caller building a numpy array of results to special-case
    missing intersections before conversion. A NaN-filled Point carries the same
    "no result" information, converts to a numpy array without special-casing,
    and is ignored by matplotlib / filterable with np.isnan.
    Also removes the unused duplicate line_segment_intersection/ray_intersection
    in tracing/ray.py: dead code left over from before the intersection logic
    was split into tracing/intersection.py, never imported or called anywhere,
    and quietly diverged (wrong threshold**2 handling, no NaN fix) from the live
    version.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
2026-07-30 feat: add duct-geometry example notebook
    Advanced example covering STL-based multi-material geometry, dual-laser
    stage placement, sampling + GradientBoostingEstimator + Optimizer for the
    inverse problem, a snake-ordered calibration grid, and G-code export.
    Includes only the two STL files the notebook actually loads
    (simple-octagone-{outer,inner}.stl); the surrounding example-data STL files
    stay untracked for now.
    [simple-octagone-inner.stl, simple-octagone-outer.stl]
2026-07-30 docs: rewrite README for a new maintainer
    Adds installation, a working quickstart, an architecture/core-concepts
    overview, and a project-status table, replacing the old concept-only
    README. Documents both example notebooks, the inverse-optimization and
    pipe-center-finder modules, and the lcc-control-gui workspace member.
    Known Gaps section records what's genuinely missing rather than implying
    a finished pipeline: no first-class G-code generator, no geometry-module
    example, no LICENSE file yet, no CI, no partial-reflection/beam-splitting
    physics, and which example-data STL files are and aren't tracked.
2026-07-30 fix: wrap hazy-frames errors in domain-specific InvalidGeometryError
    Object construction (OpticalRay, Plane, cylinders, laser sources) let
    hazy-frames' RuntimeError propagate with library-controlled wording,
    which broke tests when a hazy-frames update changed its error messages.
    Catch those errors at each construction boundary and re-raise as our
    own InvalidGeometryError, decoupling the public API and tests from
    hazy-frames' internal message text.
